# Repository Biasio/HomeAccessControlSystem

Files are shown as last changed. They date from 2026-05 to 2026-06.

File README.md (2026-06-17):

# Home Access Control System 

<!-- TABLE OF CONTENTS -->
<details>
  <summary>Table of Contents</summary>
  <ol>
    <li><a href="#about-the-project">About The Project</a></li>
    <li><a href="#repository-structure">Repository Structure</a></li>
    <li><a href="#hardware-setup">Hardware Setup</a></li>
      <ul>
            <li><a href="#1-rfid-reader">1. RFID Reader</a></li>
            <li><a href="#2-stepper-motor">2. Stepper Motor</a></li>
            <li><a href="#3-display---crystalfontz-128x128-tft-lcd-boostxl-edumkii-onboard">3. Display - Crystalfontz 128x128 TFT LCD (BOOSTXL-EDUMKII Onboard)</a></li>
            <li><a href="#4-input-peripherals-buttons--joystick-boostxl-edumkii-onboard">4. Input Peripherals: Buttons & Joystick (BOOSTXL-EDUMKII Onboard)</a></li>
            <li><a href="#5-piezo-buzzer-boostxl-edumkii-onboard">5. Piezo Buzzer (BOOSTXL-EDUMKII Onboard)</a></li>
            <li><a href="#6-vl53l0x---distance-sensor">6. VL53L0X - Distance Sensor</a></li>
            <li><a href="#7-esp32-s3-uart-communication">7. ESP32-S3 UART Communication</a></li>
            <li><a href="#project-wiring">Project wiring</a></li>
        </ul>
        <li><a href="#software-setup">Software Setup</a>
          <ul>
            <li><a href="#ccstudio-and-simplelink">CCStudio and Simplelink</a></li>
            <li><a href="#telegram-bot">Telegram Bot</a></li>
            <li><a href="#visual-studio-code--platformio">Visual Studio Code + PlatformIO</a></li>
          </ul>
        </li>
      </ul>
    <li><a href="#user-guide">User Guide</a></li>
    <li><a href="#authors">Authors</a></li>
  </ol>
</details>

## About The Project
Welcome to the Home Access Control System!

This project implements a smart door access control system that combines local hardware interaction with IoT remote management.
Users can authenticate using unlock codes, while the administrator can access a dedicated secure menu using an RFID tag.
Beyond the physical interface, an integrated Telegram bot handles remote interactions, enabling the administrator to oversee access permissions and allowing users to request or manage their own codes.
The system also features a database that logs all access events for monitoring purposes.

## Repository Structure

```text
.
├── 3D-Model/                                 # Hardware 3D printable components
│   ├── All components.3mf                    # All components in 1 file
│   ├── door.stl                              # Door model
│   ├── doorframe.3mf                         # Door frame model
│   ├── gear.stl                              # Gear mechanism model
│   ├── sensors_and_peripherals_supports.scad   # OpenSCAD parametric supports
│   └── sensors_and_peripherals_supports.stl    # Exported supports model
├── RepoImages/                               # Documentation media and images
│   ├── HardwareSetup/                        # Schematic diagram
│   ├── SoftwareSetup/                        # Software Setup screenshots
│   │   ├── CCStudio/                         # CCStudio IDE
│   │   ├── FSM/                              # FSM diagram
│   │   └── VSCode+PlatformIO/                # VSCode and PlatformIO IDE
│   └── TelegramBot/                          # Bot usage demonstrations (GIFs & Images)
├── ShortStaysAccessControlSystem/            # Firmware project (MSP432 Microcontroller)
│   ├── msp432p401r.cmd                       # Memory linker script
│   ├── src/                                  # Source code directory
│   │   ├── external_src/                     # External hardware libraries
│   │   │   ├── LCD/                          # Display graphics library
│   │   │   │   ├── Crystalfontz128x128_ST7735.c / .h                     # ST7735 controller primitives
│   │   │   │   └── HAL_MSP_EXP432P401R_Crystalfontz128x128_ST7735.c / .h # Display pin mapping
│   │   │   └── vl53l0x_msp432/               # Distance sensor submodule (Git)
│   │   │       ├── drivers/                  # Sensor native API registers
│   │   │       │   ├── config.h              # Timing configuration
│   │   │       │   ├── i2c.c / .h            # I2C driver
│   │   │       │   ├── macro.h               # Internal macros
│   │   │       │   └── vl53l0x.c / .h        # Main ranging core
│   │   │       ├── main.c                    # Sensor standalone test
│   │   │       └── README.md                 # Submodule info
│   │   ├── buzzer.c / .h                     # Buzzer acoustic alerts
│   │   ├── comm_esp.c / .h                   # Serial communication with ESP32
│   │   ├── database.c / .h                   # Local access credentials memory
│   │   ├── display.c / .h                    # LCD high-level UI menus
│   │   ├── flash.c / .h                      # Flash memory storage driver
│   │   ├── fsm_helpers.c / .h                # State machine utilities
│   │   ├── fsm.c / .h                        # Main application logic (FSM)
│   │   ├── irqHandlers.c / .h                # Hardware interrupt routines
│   │   ├── joystick.c / .h                   # Analog joystick driver
│   │   ├── main.c                            # System entry point & loop
│   │   ├── motor.c / .h                      # Motor control driver
│   │   ├── push_button.c / .h                # Buttons and debouncing
│   │   ├── sensors.c / .h                    # RFID and Distance sensor drivers
│   │   └── timers.c / .h                     # Periodic timer configurations
│   ├── startup_msp432p401r_ccs.c             # Microcontroller vector table
│   ├── system_msp432p401r.c                  # System clock configuration
│   └── targetConfigs/                        # IDE target configurations
│       ├── MSP432P401R.ccxml                 # Target configuration file
│       └── readme.txt                        # Target config info
├── TelegramBot/                              # PlatformIO project (ESP32 Microcontroller)
│   ├── include/                              # Global header files
│   │   ├── credential-template.h             # Wi-Fi and Token template
│   │   └── README.md                         # Folder info
│   ├── lib/                                  # Custom local libraries
│   │   ├── DoorBotManager/                   # Telegram connection & events logic
│   │   │   ├── DoorBotManager.cpp            # Bot API implementation
│   │   │   └── DoorBotManager.h              # Bot class definition
│   │   └── README.md                         # Lib folder info
│   ├── platformio.ini                        # Build and dependency settings
│   ├── src/                                  # Application source code
│   │   ├── idf_component.yml                 # ESP-IDF component packages
│   │   └── main.cpp                          # Main bot loop & Wi-Fi init
│   └── test/                                 # Unit testing folder
│       └── README.md                         # Test folder info
├── HomeAccessControlSystem-Presentation.pdf  # Project presentation
└── README.md                                 # Project documentation
```

## Hardware Setup 

To securely isolate local hardware operations from network tasks, the system architecture is divided between two interconnected microcontrollers:

- **Texas Instruments MSP432P401R**: The core of the system, interfaced with the **Educational BoosterPack MKII (BOOSTXL-EDUMKII)**. It handles several external and onboard sensors and actuators to manage physical access control and user interaction.

- **Espressif ESP32-S3**: Operating as a dedicated network coprocessor, it connects to the MSP to handle all Wi-Fi connectivity, system time synchronization, and the Telegram Bot logic.

Below is the technical breakdown of each hardware module integrated into the system, including their designated communication protocols, pin mapping, and core logic.

### 1. RFID Reader
Handles secure tag scanning and authentication, granting administrator-level access to the local configuration menu.

* **Communication Protocol:** `SPI`
* **Hardware Connections:**
  * `SDA / CS`: Pin `[5.2]`
  * `SCK`: Pin `[3.5]`
  * `MOSI`: Pin `[3.6]`
  * `MISO`: Pin `[3.7]`
  * `RST`: Pin `[3.0]`

#### Core Implementation

##### Initialisation (`RFID_Init`)
```c
Configure SPI pins (SCK, MOSI, MISO, CS, RST) as peripherals
Set CS high (idle)
Pull RST low for 1 ms, then high (hard reset)
Set SPI master: 4 MHz, mode 0, MSB first
Keep SPI module disabled (RFID_ready = false)
```

##### Enable (`RFID_Enable`)
```c
if not RFID_ready:
    RFID_Init()
Enable SPI module
Set RST high, delay 50 ms for boot up

Soft reset MFRC522

Verify version (0x37) == 0x91 or 0x92, if invalid: return false

Configure the onboard timer
Set RxGain
Enable the antenna: set bit0 and bit1 of TxControlReg (0x14)

RFID_ready = true 
return true
```

##### Disable (`RFID_Disable`)
```c
Set CS high
Disable SPI module
Set RST high (inactive)
Restore pins as inputs with pull‑ups (shared with the A_button)
Re‑initialise display and buttons
RFID_ready = false
```

##### Read Tag (`RFID_ReadTag`)
```c
REQA request, if response length < 2 bytes: return false

Anticollision command - multiple cards could be present at the same time. If response length < 5 bytes: return false

Checksum check, if it fails return false

return the UID
```

##### Tag Validation & Error Handling

**Used for standard admin access (in `wait_RFID` or `block_RFID`)**
```c
if not RFID_Enable() show "ERROR" and return false

while true:
    if buttonA_pressed: 
        RFID_Disable(); return false   // cancel (for wait_RFID only)

    if RFID_ReadTag(uid, &len) succeeded:
            if the tag is valid and correct:
	    	show "VALID RFID" and play the correct sound
            	return true
	    else:
		RFID_Disable()
	        show "WRONG RFID", play wrong sound
	        return false
    else:
        delay_ms(50)    // no tag, keep polling after a short delay
```

**Error checks and resilience**:
The RFID driver includes exhaustive checks for every SPI transaction (timeouts, protocol errors, collisions, CRC mismatches, and FIFO emptiness) and validates the UID checksum before accepting a read.
If a critical error occurs (e.g., version mismatch after soft reset), it automatically re‑initialises the module; otherwise, it safely disables the SPI interface and restores pin functions, preventing hangs or bus conflicts.

### 3. Stepper Motor
Actuates the physical locking and unlocking mechanism of the door via precise rotational control.

* **Communication Protocol:** `ULN2003 driver`
* **Hardware Connections:**
  * `IN1`: Pin `[2.5]`
  * `IN2`: Pin `[6.6]`
  * `IN3`: Pin `[6.7]`
  * `IN4`: Pin `[2.3]`

#### Core Features
* **Angle-based Control:** Converts a given angle into the number of steps required by the 28BYJ-48 Stepper Motor. 
* **Safe locking/unlocking Mechanism:** Saving in Flash memory a dedicated flag, ensures protection against two straight opening (or closing) cycles which can damage door mechanism. Pretty useful in case of power failure. 
* **Full-Step Drive:** Supplying power to two coils simultaneously, the Motor gives the maximum available torque and holding force. This ensures reliability when opening/closing the door. 
* **External Power Supply:** To avoid over-heating and self-reset procedure on the MSP-board due to over-current demanding, the Motor Driver is feed with an external 5V Power Source.

#### Core Implementation
```c
moveMotor(int angle):      //This function converts the given angle into the number of steps required and manages motor movement
    calculate number of steps required to turn motor on the given angle    
    
    if the number of steps is negative:
        Motor needs to run counterClockwise
    else:
        Motor runs clockwise

    calculate index for the For-cycle, depending in which direction Motor should run

    for each step Motor will make:

        for each pin:
          
          if the associated coil should go high:
            Set pin high
          else:
            Set pin low

        wait before the next step

   before returning from the function, set all pins low  
```

### 3. Display - Crystalfontz 128x128 TFT LCD (BOOSTXL-EDUMKII Onboard)

The **Crystalfontz CFAF128128B-0145T color 128x128-pixel TFT LCD** renders the local Graphical User Interface (GUI), to display the keypad interface and the admin menu.

* **Communication Protocol:** `SPI`
* **Hardware Connections:**
  * `LCD_SCLK`: Pin `P1.5`
  * `LCD_MOSI`: Pin `P1.6`
  * `LCD_CS`: Pin `P5.0`
  * `LCD_RST`: Pin `P5.7` 
  * `LCD_BACKLIGHT`: Pin `P3.7` 

#### Core UI Features
* **Numeric PIN Grid:** Renders a 3x4 interactive keypad interface for standard user authentication.
* **Administrator Menu:** A scrollable, paginated menu allowing authorized admins to view the last access log and manually lock and unlock the door and clear the database.
* **Dynamic Joystick Navigation:** Translates raw X/Y analog inputs from the joystick to move a red selection rectangle (`Rectangle` struct) across the screen, supporting both grid-based navigation and vertical menu scrolling.
* **Interactive Selection & Feedback:** Evaluates the position of the selection rectangle against a predefined array of coordinates (e.g., `GRID_POINTS`). When a user confirms a selection, the system executes a temporary visual flash (red-to-white fill) over the selected item to provide immediate confirmation feedback.
* **System Status Prompts:** Delivers instant, color-coded visual alerts for real-time events (e.g., `display_door_open()`, `display_wrong_pin()`, `display_block_access()`).

#### Core Implementation

```c
// Initialize the graphics context, display orientation, and default fonts
graphicsInit():
    initialize LCD hardware
    set colors, font and orientation UP

// Routes joystick input to update the UI based on the active screen state
move_rectangle_on_display(x, y, grid_on):
    if grid_on:
        calculate bounds and shift selection box across numeric keypad
    else:
        handle vertical scrolling, pagination, and highlighting in Admin Menu

// Detects selected grid point and triggers visual feedback
number_selected():
    for each point in GRID_POINTS:
        if the point is inside the selection rectangle:
            trigger visual flash feedback
            return point_index        
    return -1    // no number selected

```

### 4. Input Peripherals: Buttons & Joystick (BOOSTXL-EDUMKII Onboard)
Captures analog and digital user inputs for menu navigation, selection, and system interaction. 

* **Communication Protocol:** `GPIO` (Digital Input with Interrupts) & `ADC` (Analog-to-Digital Converter)
* **Hardware Connections:**
  * `Button 1`: Pin `P5.1`
  * `Button 2`: Pin `P3.5`
  * `Joystick X-Axis`: Pin `P6.0`
  * `Joystick Y-Axis`: Pin `P4.4`

#### Core Features
* **Interrupt-Driven Architecture:** Utilizes hardware interrupts for both the ADC (joystick) and GPIO (buttons) to capture inputs asynchronously. This prevents the system from blocking the main execution loop while waiting for user interaction.
* **Pull-Up Configuration:** Pushbuttons are configured with internal pull-up resistors, meaning they trigger on a high-to-low voltage transition (active-low) when pressed.
* **Timer-Based Software Debouncing:** To prevent mechanical switch bounce from registering as multiple rapid presses, the system temporarily disables the button interrupt and triggers a hardware timer. The input state is only validated after the timer expires.

#### Core Implementation
```c
ADC_interrupt():
    if conversion_finished:
        joystick_X = read_ADC(X_channel)
        joystick_Y = read_ADC(Y_channel)
        set move_rectangle_flag       // trigger UI update
        restart joystick_timer

GPIO_button_interrupt():
    if button1_triggered:
        initiate_debounce_sequence()
        return

initiate_debounce_sequence():
    disable button interrupts         // ignore mechanical switch bounce
    start debounce_timer              // wait for signal to stabilize

debounce_timer_interrupt():
    stop debounce_timer

    if button1 is still pressed:
        set button1_pressed_flag
        reset UI_timeout_timer

    if button2 is still pressed:
        set button2_pressed_flag
        reset UI_timeout_timer

    re-enable button interrupts       // ready for next press
```

### 5. Piezo Buzzer

Generates acoustic feedback for successful actions (correct PIN, valid RFID), wrong attempts, and system lockout.
Comes with a configurable VOLUME 
* **Communication Protocol:** `PWM` (Pulse Width Modulation)
* **Hardware Connections:**
  * `Signal`: Pin `P2.7` (Timer_A0 capture/compare output 4)

#### Core Implementation

##### Initialisation (`_buzzerInit`)
```c
Stop Timer_A0
Disable the timer interrupts and clear any pending interrupt flag
Configure P2.7 as peripheral output (primary module function)
```

##### PWM Configuration Structure
```c
Timer_A_PWMConfig {
    clockSource: SMCLK
    clockDivider: 16
    timerPeriod: calculated as a function of the notes
    compareRegister: 4
    outputMode: RESET_SET
    dutyCycle: calculated as a function of the notes
}
```

##### Play a Song (`buzzerPWMgen`)
```c
For each note in the song:
    if volume != 0 and freq != 0:
        timerPeriod = ((SMCLK frequency) / (freq × 16)) & (0xFFFF) // clamped to 16‑bit]
        dutyCycle = (timerPeriod × volume) >> 10
        Configure and start PWM with this period/duty
        delay for the note.duration
        dutyCycle = 0 → stop PWM
        delay_ms(1)   // short silence between notes
    else:
        Stop timer (no sound)
```
All sequences are blocking (delay-based) and play to completion before returning control to the caller.

##### Pre‑defined Sounds

| Sound         |
|---------------|
| `CorrectPin`  |
| `WrongPin`    |
| `LockOut`     |
| `CorrectRFID` |

### 6. VL53L0X - Distance Sensor
Detects user proximity to wake the system from low‑power mode, configured to trigger an interrupt when a target is closer than 300 mm (src/external_src/vl53l0x_msp432/drivers/config.h).

* **Communication Protocol:** `I²C`
* **Hardware Connections:**
  * `SCL`: Pin `P6.5`
  * `SDA`: Pin `P6.4`
  * `XSHUT`: Pin `P4.1` (hardware reset / power enable)
  * `INTERRUPT`: Pin `P4.6` (active‑low)

#### Core Implementation

##### Initialisation (`ToF_Init`)
```c
Configure XSHUT as output, pull low (sensor in reset)
Initialise I²C master (EUSCI_B1, speed: 400 kHz, clk source: SMCLK)
Configure interrupt pin as input with pull‑up, edge‑triggered (falling edge)
```

##### Enable (`ToF_enable`)
```c
Release XSHUT (high) and wait for sensor boot
vl53l0x_init():
    - I²C slave address set to default address (0x29)
    - load SPAD configuration from NVM
    - Load default tuning settings
    - Set signal rate limit (0.25 MCPS) and timing budget (33 ms) for average light conditions
    - Run VHV and phase calibrations

Call vl53l0x_start_continuous(): arms continuous back‑to‑back ranging

Clear any pending interrupt on sensor

Enable GPIO interrupt on P4.6

ToF_ready = true
```

##### Disable (`ToF_disable`)
```c
Disable GPIO interrupt on P4.6

Call vl53l0x_stop_continuous() halts the ranging engine and clears interrupt register

Pull XSHUT low (sensor in hardware standby)

ToF_ready = false
ToF_flag = 0
```

##### Interrupt Handling (`ToF_IRQHandler`)
```c
Disable further interrupts on P4.6
Clear interrupt flag on GPIO

If ToF_ready: set ToF_flag = 1
```

##### Proximity Detection Flow
```c
System in `STATE_AOD` with sensor enabled

User approaches, sensor crosses 300 mm threshold and INT pin asserts

`ToF_flag` set so `check_for_inputs()` evaluates the ToF reading via `vl53l0x_read_range_interrupt()`

If range ≤ low_threshold && the error code is valid:
	 disable the sensor and wake system to `STATE_INSERT_PIN`
   else:
	reactivate the interrupt for ToF and go to sleep
```
#### Error checks and resilience
The VL53L0X driver implements automatic init retries (up to 2 attempts) if initialisation or continuous ranging start fails. 
Every I2C transaction includes NACK detection and timeout checks to prevent hanging or corrupted configuration in registers I/O operations.

### 7. ESP32-S3 UART Communication

An `UART` serial communication interface was configured to enable data exchange and command execution between the two microcontrollers.

* **Communication Protocol:** `UART`

* **Hardware Connections:**
  * Texas Instruments MSP432P401R:
    * TX: Pin `P3.3`
    * RX: Pin `P3.2`
  * Espressif ESP32-S3:
    * TX: Pin `P17`
    * RX: Pin `P16`

#### Core Features

* **Message Handling & Dispatching:** Uses hardware interrupts (`EUSCIA2_IRQHandler`) to asynchronously buffer incoming messages and routes them to specific handlers based on predefined prefixes (`processUartMessage`).

* **PIN Management:** Manages access by generating unique 4-digit PINs (`handleGenTempPin`), verifying user inputs against stored credentials (`handleVerifyPin`), and processing early revocation requests (`handleRevokePin`).

* **Time Synchronization:** Requests network time (`requestRealTime`) and parses the ESP32 payload to accurately configure the hardware Real-Time Clock (`handleTimeSync`).

### Project wiring
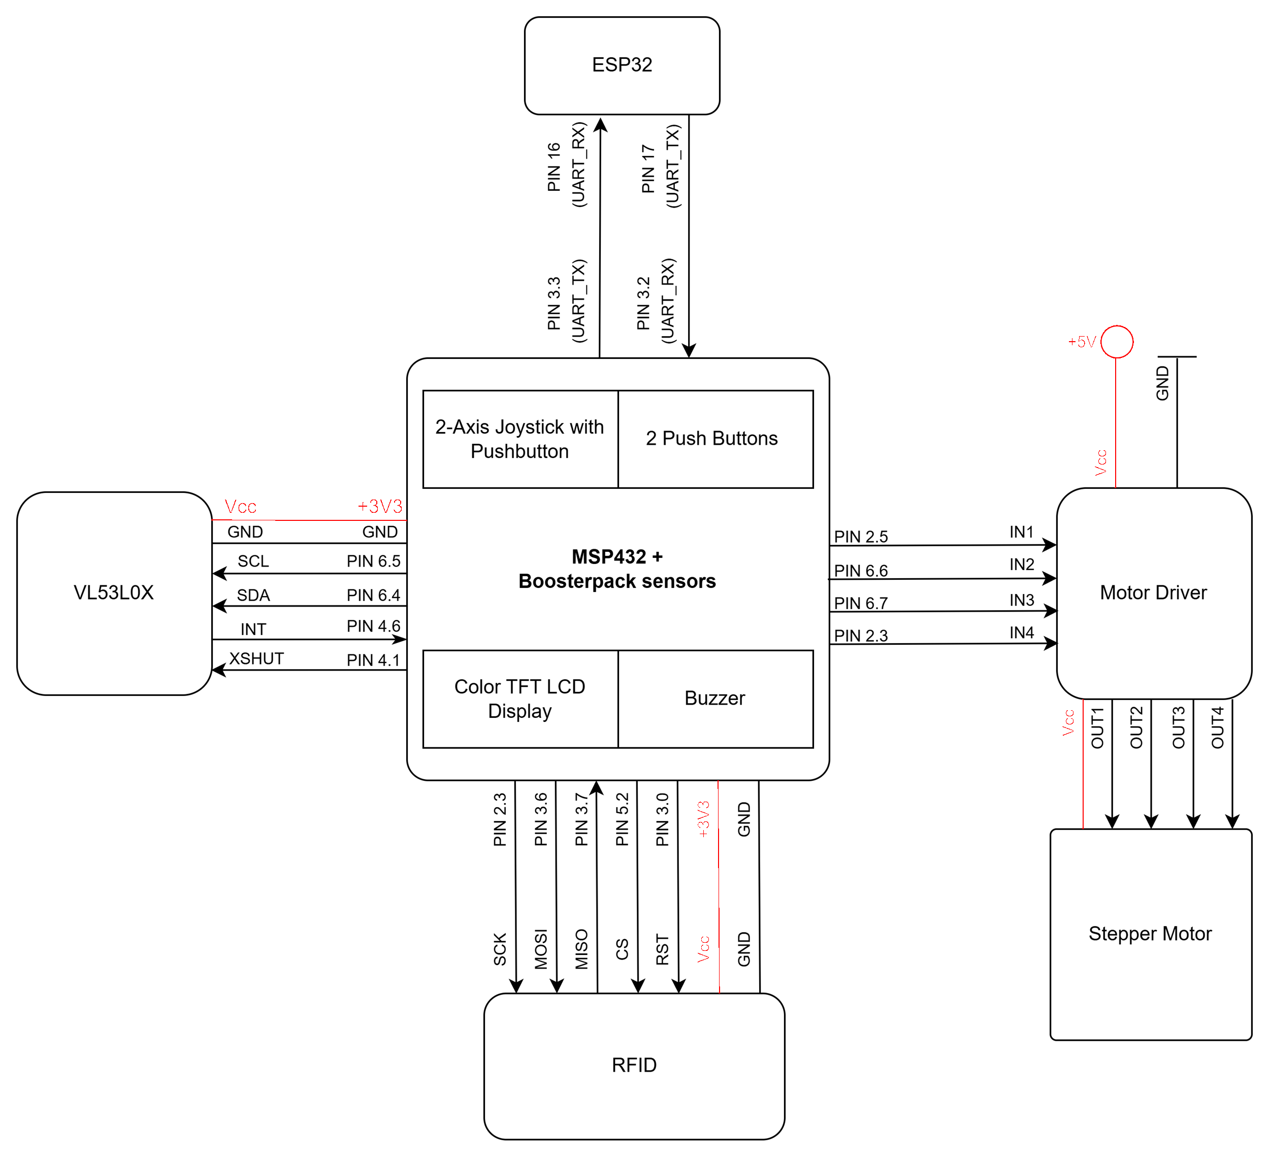
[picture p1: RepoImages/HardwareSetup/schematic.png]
Schematic of the project


## Software Setup

### CCStudio and Simplelink

1. First, clone the repository with git

```bash
git clone <repository-url>
cd <repository-folder>
git submodule init && git submodule update --remote
```

2. Then download [**CCStudio v12.8**](https://www.ti.com/tool/download/CCSTUDIO/12.8.1) and [**SimpleLink MSP432 SDK v3.40.01.02**](https://www.ti.com/tool/download/SIMPLELINK-MSP432-SDK/3.40.01.02)

> ⚠️ **Important:** The SimpleLink SDK must be placed in the **parent directory** of the repository (i.e., the folder that will contain the cloned repo). For example, if you pln
 to clone into `~/my_project`, the SDK should be extracted to `~/` (so the SDK folder sits alongside `my_project`, not inside it).

3. Now you can import the project in CCStudio:
    - Launch **CCStudio v12.8**
    - When prompted for a workspace, select the **repository folder** (the one you just cloned)
    - Go to **Project → Import Project** (or **File → Import** → **CCS Projects**)
    - Click **Browse…** and select the repository folder
    - Under **Discovered Projects**, check the project you want to import
    - Click **Finish**

4. The MSP432 program can be now uploaded to the board.

### Telegram Bot

1. Download and install Telegram on your device. We recommend using the [Telegram Desktop application](https://desktop.telegram.org/) on your PC for a more comfortable setup experience.
Open this link [**@BotFather**](https://t.me/BotFather) to launch the official bot creation tool in Telegram, then start the conversation by sending the command `/start`.
3. Send the command `/newbot` to create a new bot.
4. Follow **@BotFather**'s instructions to configure your bot:
   * First, choose a **name** for your bot (this is the display name users will see).
   * Then, choose a unique **username** (it must end with `bot`, e.g., `HomeAccess_bot`).
5. Once the bot is created, BotFather will send you a confirmation message containing your **HTTP API Token**. Copy and save this token securely, as you will need to insert it into the project file for the ESP firmware, as explained in the following section.
6. To configure the bot's menu, send the command `/setcommands` to **@BotFather**.
7. Select your newly created bot from the provided list, then copy and paste the following text into the chat to set up your commands:

```
start - Initialize the bot and authenticate yourself
menu - Display the main control panel and available features
cancel - Abort the current operation or transaction
```

### Visual Studio Code + PlatformIO

1. Download and install [Visual Studio Code](https://code.visualstudio.com/download).
2. Install the [PlatformIO IDE Extension](https://docs.platformio.org/en/latest/what-is-platformio.html) from the VSCode extensions marketplace.

<p align="center">
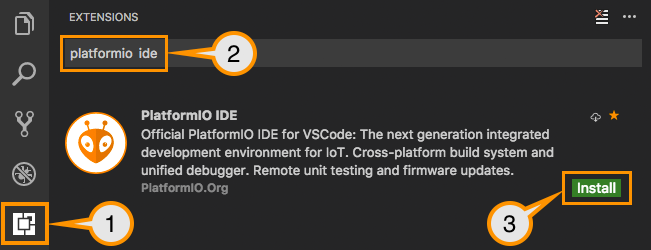
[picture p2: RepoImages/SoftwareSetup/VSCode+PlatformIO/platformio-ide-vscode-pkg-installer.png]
  
</p> 

3. Click the PlatformIO icon on the left sidebar. You will see the screen shown in the image below. Click the **Pick a folder** button. Navigate to the location where you cloned the `HomeAccessControlSystem` repository and select the `TelegramBot` folder inside it to open the project.

<p align="center">
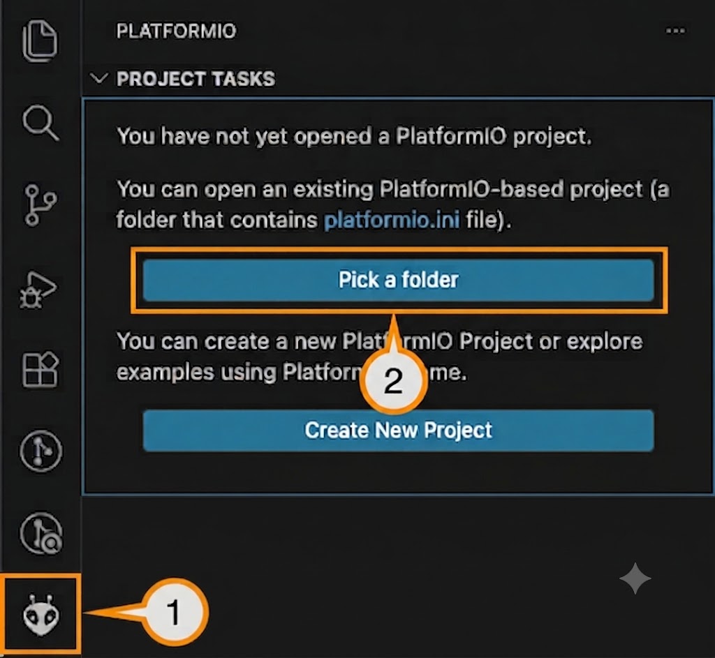
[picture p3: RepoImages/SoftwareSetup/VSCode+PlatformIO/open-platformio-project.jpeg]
  
</p> 

4. Open the configuration file located at `TelegramBot/include/credential-template.h` starting from the root of the repository.

5. Insert your Wi-Fi credentials and the Telegram Bot token you saved earlier by replacing the placeholder text inside the quotes "":

<p align="center">
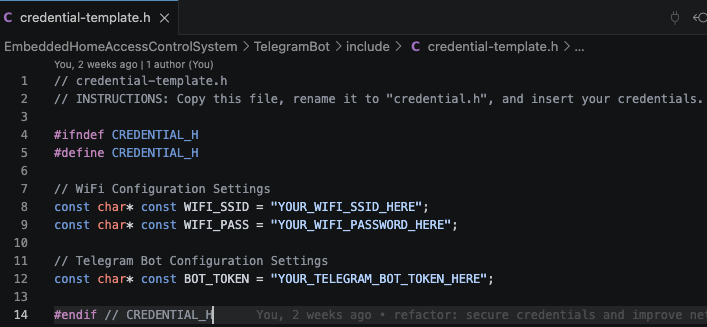
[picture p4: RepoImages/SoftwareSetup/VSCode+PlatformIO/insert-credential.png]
  
</p> 

6. Copy and rename the file from `credential-template.h` to `credential.h`. This ensures your sensitive credentials are not accidentally uploaded to GitHub if you push your changes, as `credential.h` is already included in the `TelegramBot` project's `.gitignore` file.

7. Connect a microUSB cable to the **UART** port on your **ESP32-S3 board**. Go to the top right corner where the **Build** icon (the checkmark) is located, click the down arrow symbol next to it, and select **Upload** to compile the code and upload the firmware.

> **Note:** The first time you perform this action, it will take some time. PlatformIO works in the background to automatically download all the necessary libraries and the updated Arduino core directly from the official Espressif repository.

## User Guide

This section explains how to interact with the system through its physical display and the Telegram bot.

Click here to watch:
- [Link to the presentation](HomeAccessControlSystem-Presentation.pdf)
- [Link to the video](https://youtu.be/aaDjH45Er1A)

### System Interface

#### 1. MSP User interface

<div align="center">
  <table border="0" style="border: none; background: none;">
    <tr style="border: none; background: none;">
      <td align="center" width="50%" style="border: none; padding: 10px;">
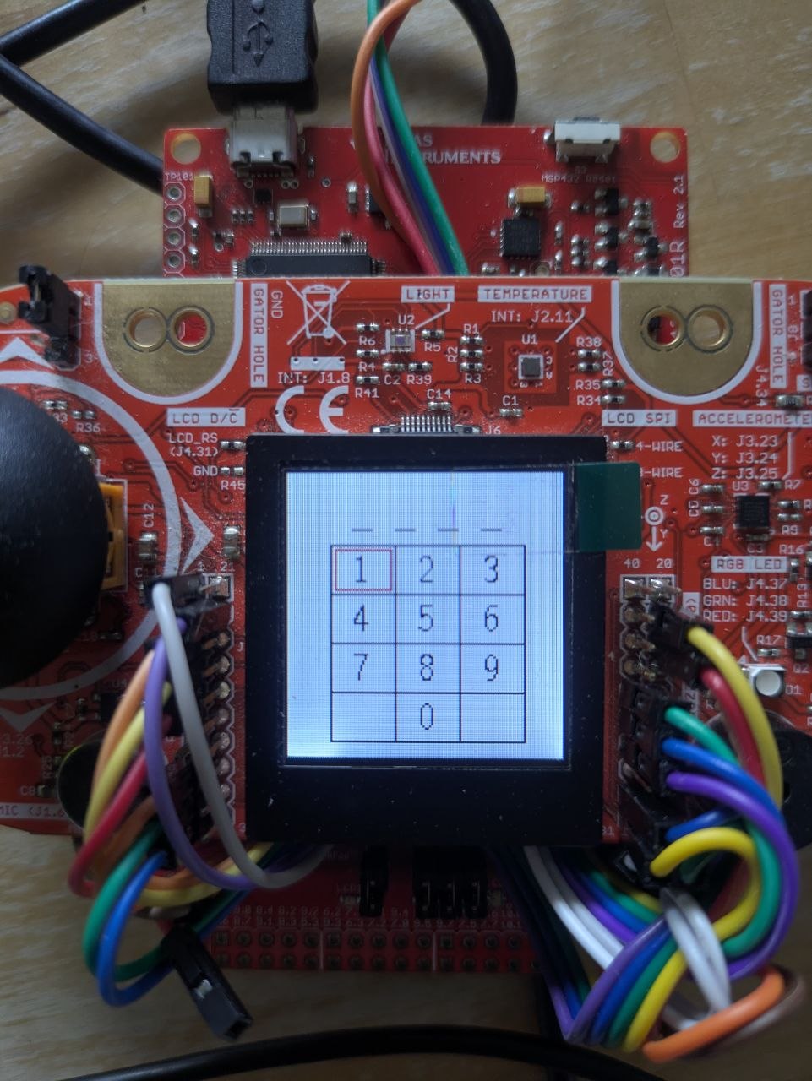
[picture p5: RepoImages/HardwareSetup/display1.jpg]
User display
        
      </td>
      <td align="center" width="50%" style="border: none; padding: 10px;">
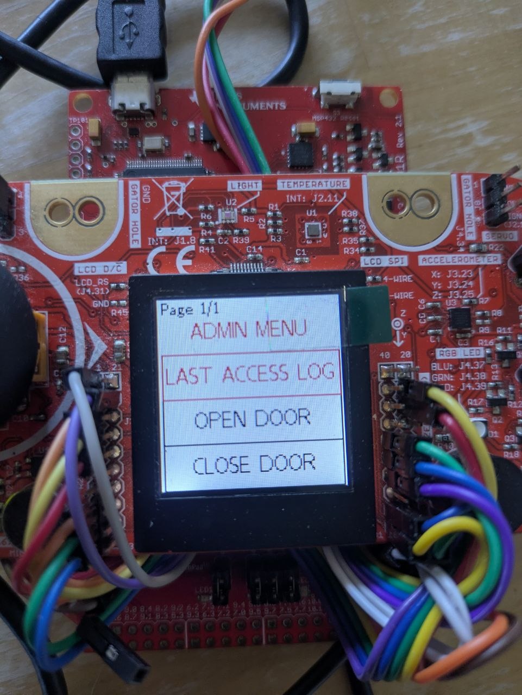
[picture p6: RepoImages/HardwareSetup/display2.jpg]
User display
        
      </td>
    </tr>
  </table>
</div>

The physical interface features an TFT LCD screen controlled by the onboard joystick and push buttons. The first image shows the numeric keypad, where users navigate to enter their 4-digit access PIN. The second image displays the Admin Menu, accessible exclusively with his PIN and RFID tag.

#### 2. Database

When logged as Admin, the system allows you to see and to navigate through an interactive “Log Database”, which stores in permanent memory (Flash) the last 10 autentication data remembering the moment of the access, the used PIN and if it has been recognised as the Admin one, as one of the Users or none.  

<p align="center">
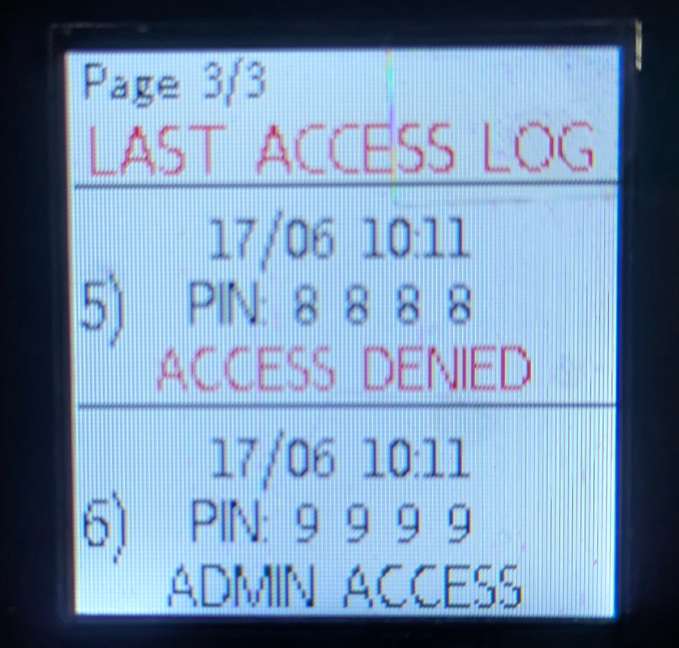
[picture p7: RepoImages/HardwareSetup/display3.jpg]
Access log page
  
</p> 

##### Core features

* **Interactive Navigation:** Using the on-board joystick, the Admin can browse the different Database pages containing all log data.

* **Quick Save:** During initialization instructions, info stored in Flash memory are copied in a RAM instance to be modified and to be shown. When a new log event is added, the systems quickly upload these modifications in the permanent memory ensuring any data lost due to power faults.

* **Blocked User Access:** The Home Access Control System checks when User access is denied multiple times, blocking it when a maximum number of tries is exceeded, until the Admin uses his RFID tag. To prevent an intruder from bypassing this check, a Boolean flag is stored in Flash memory with Database data so the system can remember, in case it’s turned off, that the Admin action is required to proceed with normal activities.

### Telegram Bot Interface

- First of all, search for your bot in Telegram using the **@username** you assigned to it during the BotFather setup (refer to the previous **Software setup section**).
- Now, you can initiate the conversation by pressing the **Start** button at the bottom of the chat or by typing the `/start` command. You will receive a prompt asking you to authenticate as either an **Admin** or a **User**.
- If you choose to log in as an **Admin**, the bot will ask for an unlock code. Currently, this code is hardcoded as `9999`.

- Once authenticated, the main command dashboard will appear. You can always bring up this dashboard again at any time by sending the `/menu` command (this applies to both Admin and Users).

<p align="center">
  
</p> 

**Admin Features**
When logged in as an Admin, your dashboard will include the following functions:
1. `Pin Duration`: Set the validity time limit for the temporary pins granted to Users.

<p align="center">
  
</p> 

2. `Remove User`: Remove a specific User entirely from the system.

<p align="center">
  
</p>

3. `Revoke all PINS`: Revoke all currently active unlock pins for all users in the system.

Beyond the dashboard, the main Admin's feature is receiving direct notifications to either approve or deny user pin requests.

<p align="center">
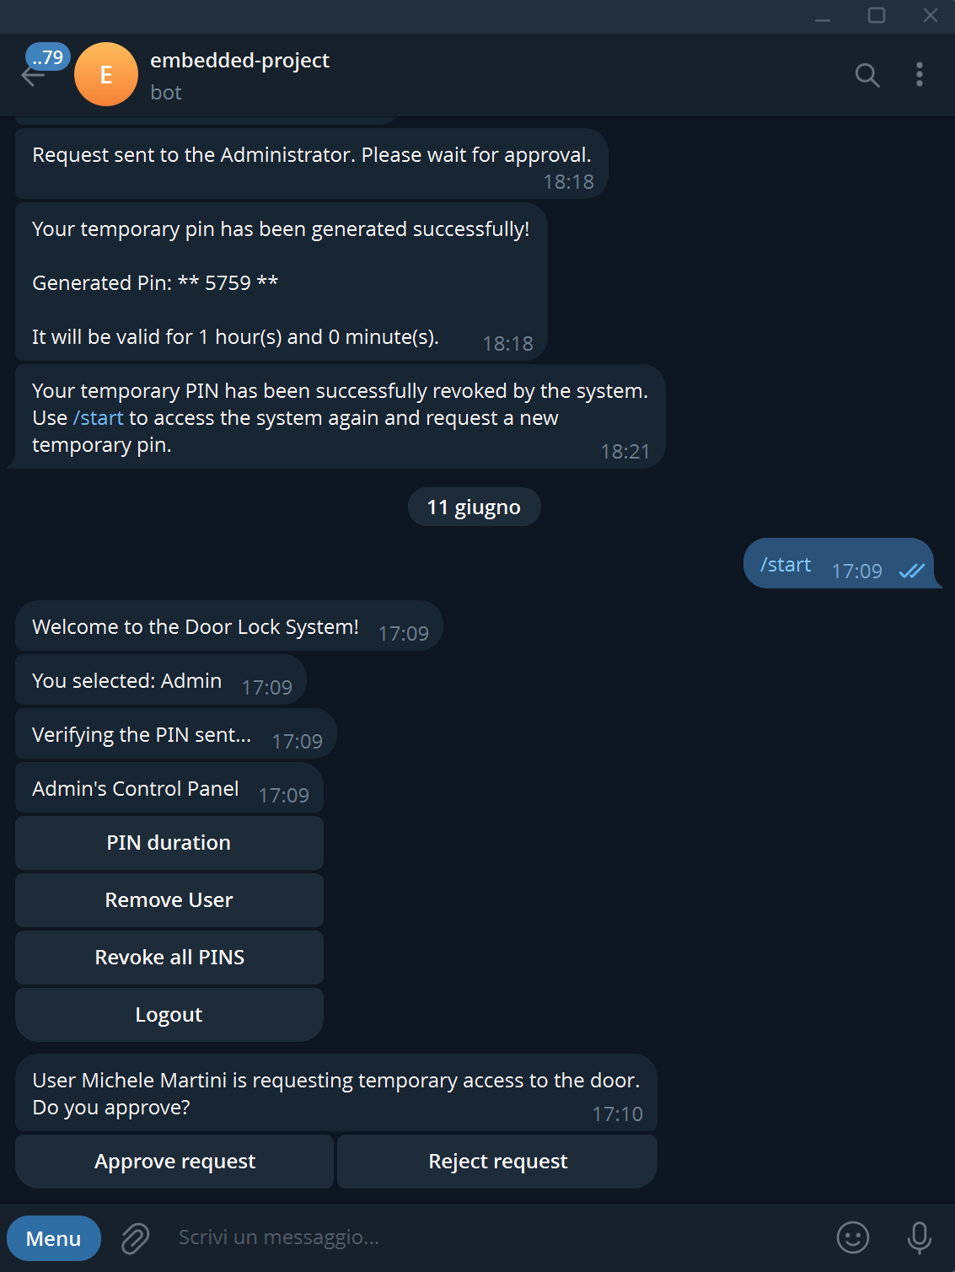
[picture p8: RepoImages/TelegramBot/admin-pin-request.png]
  
</p>

**User Features**
When logged in as a User, your dashboard adapts based on your current access status:
1. `Request Temporary Pin`: After the authentication, this is the only available action. Use it to send an access pin request to the Admin.

<p align="center">
  
</p>

2. `Temporary Pin Duration`: Once the Admin grants you a pin, use this button to check how much validity time is left before it expires.

<p align="center">
  
</p>

3. `Revoke Temporary Pin`: If you no longer need access, use this to manually revoke your own active pin early.

<p align="center">
  
</p>

## Authors

* **Pietro Baroni:**
  * MSP432 FSM structure
  * Display API and menus
  * Joystick ADC
  * Push buttons

* **Michele Martini:**
  * Telegram bot
  * ESP32 FSM
  * UART Communication

* **Michele Casagrande:**
  * Flash I/O operations
  * Database API
  * Stepper motor integration

* **Alessandro Biasioli:**
  * RFID setup, logic and communication
  * ToF Sensor bare-metal driver and logic
  * Buzzer 
  * MCU sleep and AoD logic

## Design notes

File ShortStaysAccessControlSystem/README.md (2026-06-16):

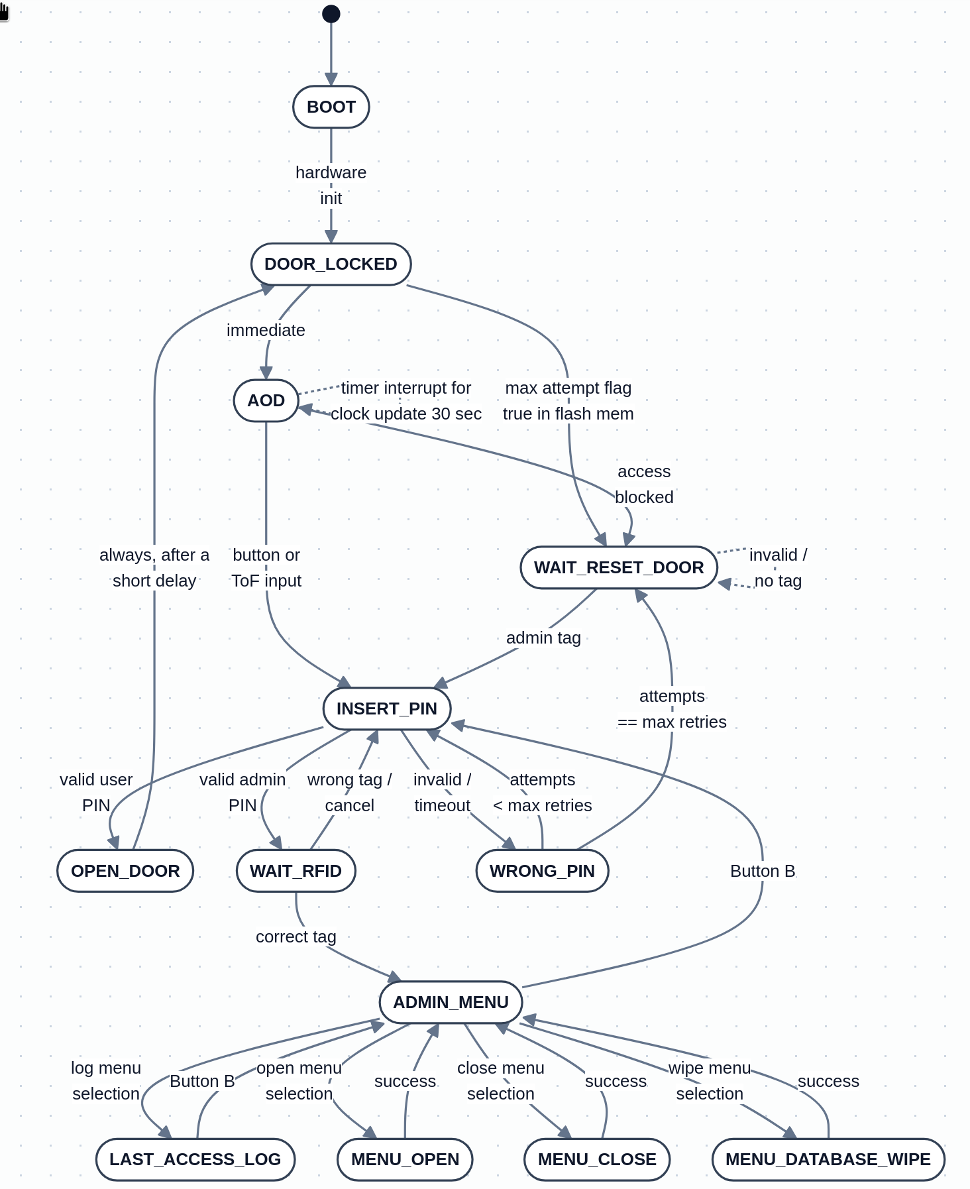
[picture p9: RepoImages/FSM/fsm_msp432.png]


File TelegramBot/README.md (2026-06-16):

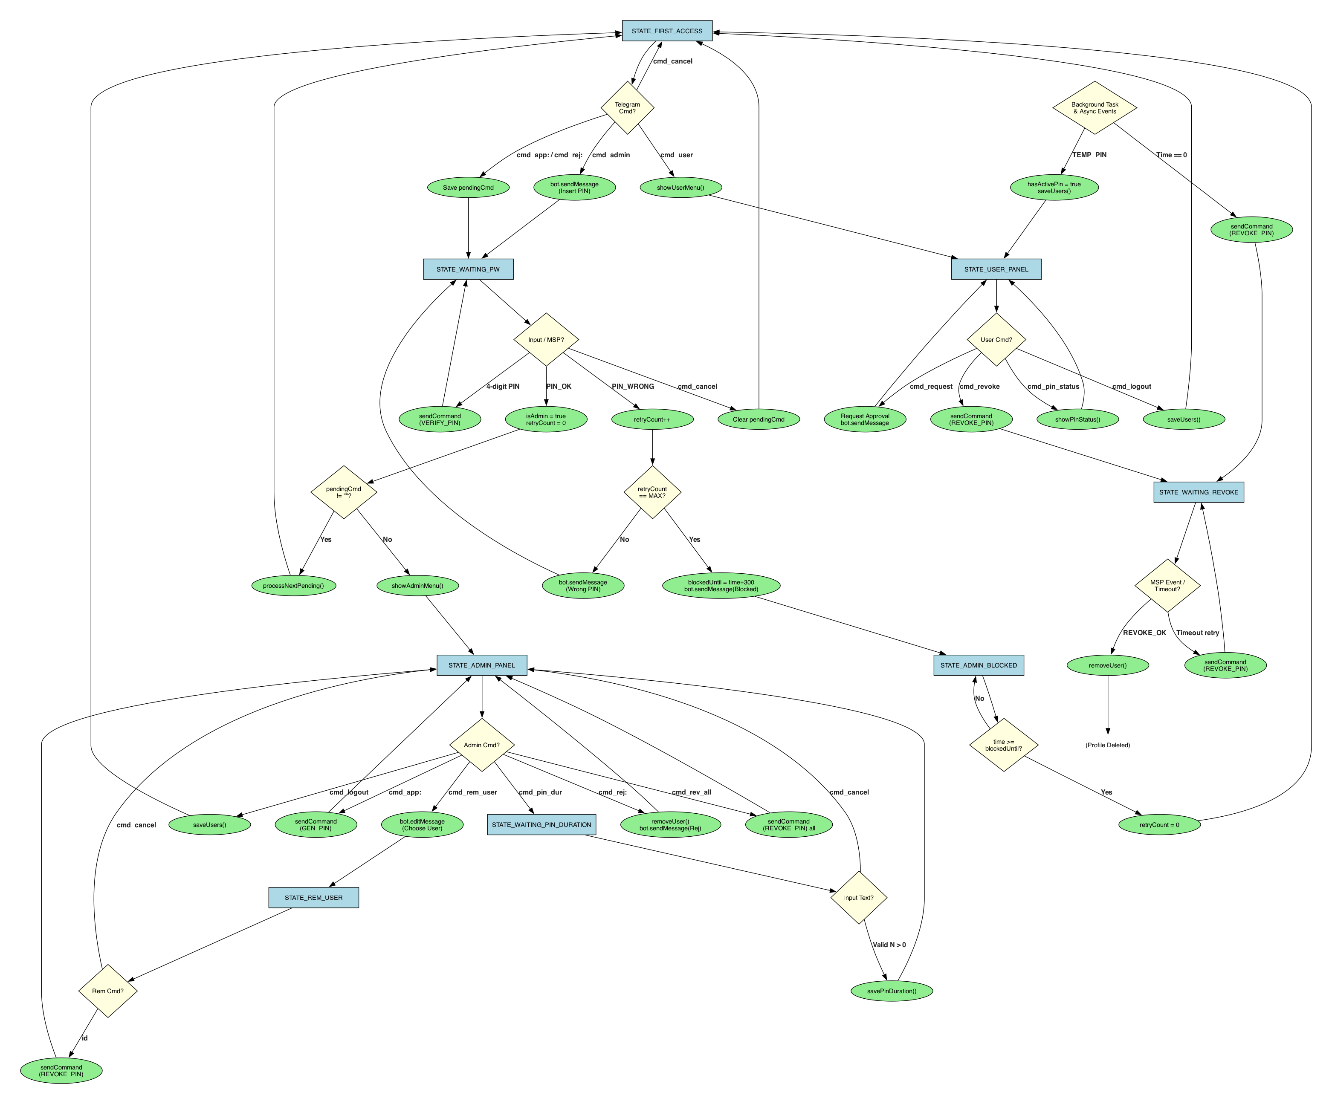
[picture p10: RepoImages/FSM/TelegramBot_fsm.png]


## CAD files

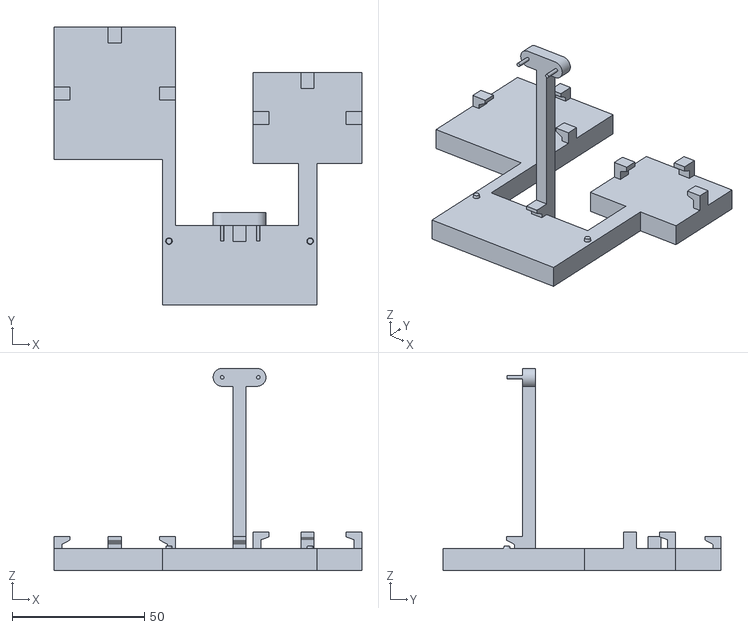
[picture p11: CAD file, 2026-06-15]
3D-Model/sensors_and_peripherals_supports_top.stl
116.6 x 105.2 x 76.6

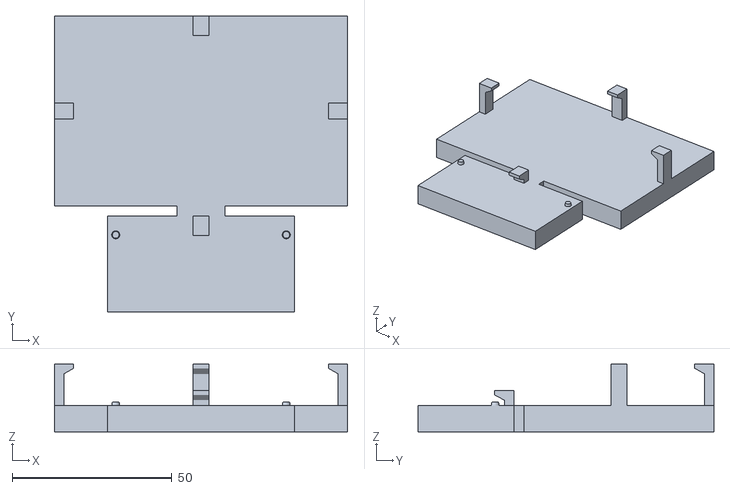
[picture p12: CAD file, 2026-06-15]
3D-Model/sensors_and_peripherals_supports_bottom.stl
91.8 x 92.7 x 21.2

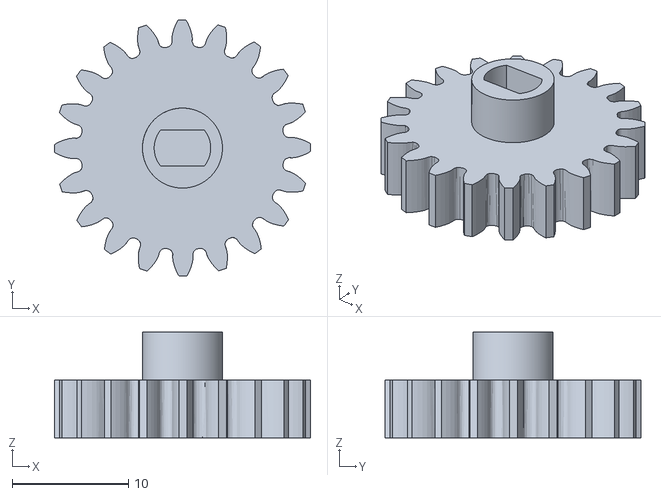
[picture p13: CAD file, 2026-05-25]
3D-Model/gear.stl
22.0 x 22.0 x 9.10

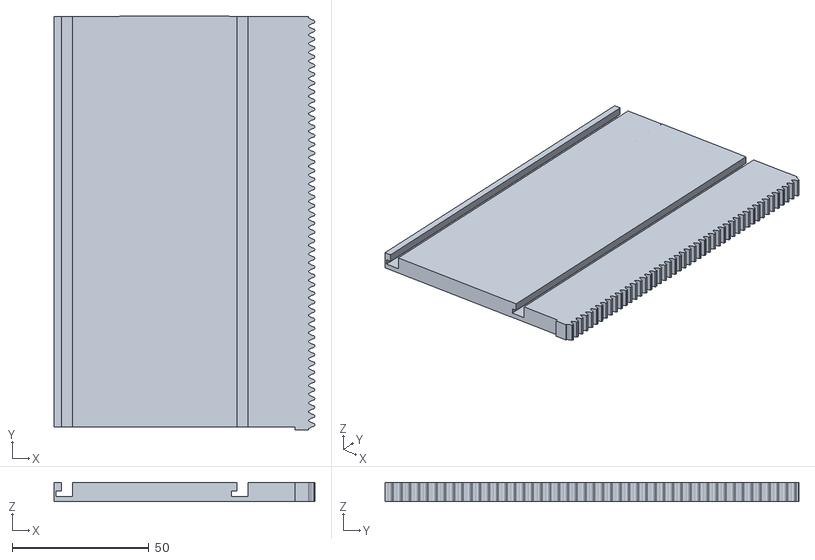
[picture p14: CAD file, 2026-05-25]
3D-Model/door.stl
95.3 x 151.0 x 7.10

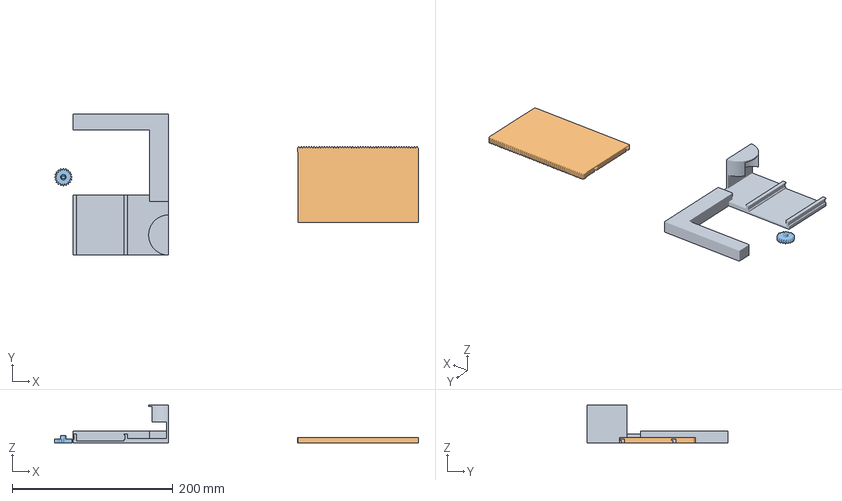
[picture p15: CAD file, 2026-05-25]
3D-Model/All components.3mf
453.6 x 176.0 x 47.3 mm
doorframe
door.stl
gear.stl

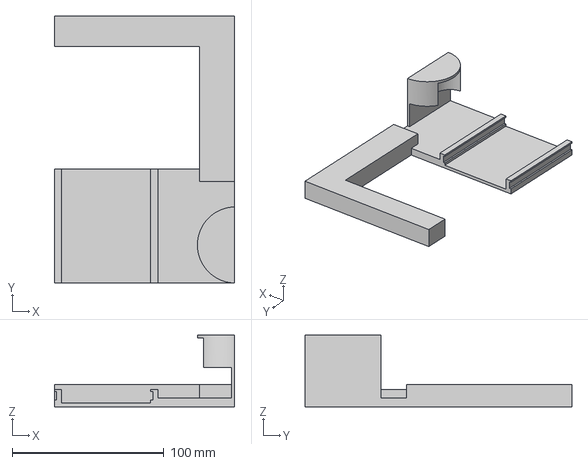
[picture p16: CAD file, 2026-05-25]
3D-Model/doorframe.3mf
118.8 x 176.0 x 47.3 mm

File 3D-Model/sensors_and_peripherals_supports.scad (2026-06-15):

$fn=100;
$fa=0.1;
//comprehensive of the diameters of the holes
board_hole_horiz_dist = 56.45;
board_hole_diameter = 3;
height_to_board = 8.3;
board_width = 58.5;
board_thickness=1.5;
base_length=30;
tolerance=0.01;

base_wall_external=2;

hole_perimeter_to_board_edge=1.2;

notch_width=5;
notch_length=3;
notch_thickness=3;
notch_height=board_thickness*1.1;




RFID_hole_to_board_distance=25;
RFID_width=40;
RFID_length=60-12.8;



vl53l0x_height=60; //from board top




// apply tolerances
fixed_board_hole_r=board_hole_diameter/2-tolerance;
fixed_height_to_board=height_to_board-tolerance;

hole_cone_base_r=fixed_board_hole_r*0.9;
hole_cone_top_r=fixed_board_hole_r*0.7;





//base cube
module base_cube(width=board_width,length=base_length,height=fixed_height_to_board){
        difference(){
            cube([width,
                length,
                height], 
                center=true);
 
            translate([0,0,-base_wall_external])
            cube([width - 2*base_wall_external,
                length - 2*base_wall_external,
                height], 
                center=true);
        }
}

//cones that will slide in the holes
module hole_cone(offset_x=0,offset_y=0,offset_z=0){
    translate([offset_x,offset_y,offset_z])
        cylinder(r1=hole_cone_base_r,
            r2=hole_cone_top_r,
            h=board_thickness*1.0,
            center=true);
}


module notch(offset_x=0,offset_y=0,offset_z=0, rotation_z=0, height=notch_height, angle=0.7){

    p0=[0,0];
    p1=[notch_thickness,0];
    p2=[notch_thickness,-height];
    p3=[notch_thickness+notch_length,-(height+notch_thickness)*angle];
    p4=[notch_thickness+notch_length,-(height+notch_thickness)];
    p5=[0,-(height+notch_thickness)];
    
    translate([offset_x,offset_y,offset_z])
    rotate([-90,0,-90+rotation_z])
    linear_extrude(height=notch_width, center=true)
    polygon([p0,p1,p2,p3,p4,p5]);
}

//base that inserts on the board
module board_base(offset_x=0,offset_y=0,offset_z=0){
    
    cone_x_offset=(board_hole_horiz_dist -board_hole_diameter)/2;
    
    cone_y_offset=(base_length/2)-hole_perimeter_to_board_edge-hole_cone_base_r-notch_thickness*1.1;
    
    cone_z_offset=(fixed_height_to_board/2)+board_thickness/4-0.001;
    
    translate([offset_x,offset_y,offset_z]){
        base_cube();
        
        hole_cone(offset_x=cone_x_offset,
            offset_y=cone_y_offset,
            offset_z=cone_z_offset);
        hole_cone(offset_x=-cone_x_offset,
            offset_y=cone_y_offset,
            offset_z=cone_z_offset);
        
        notch(0,base_length/2,fixed_height_to_board/2-0.001);
        
    }
}





module RFID(){
	//calculate size with notches
	width=RFID_width+2*(notch_thickness+tolerance);
	length=RFID_length+notch_thickness+tolerance;

	arm_width=5; // note the usb plug allows for max 5mm
	translate([arm_width/2-board_width/2,RFID_hole_to_board_distance/2-0.001+base_length/2,0])
	base_cube(arm_width,RFID_hole_to_board_distance);
	
	translate([
	width/2-board_width/2+arm_width-width,
	length/2+base_length/2+RFID_hole_to_board_distance-0.001,
	0]){
		base_cube(width,length);
		
		translate([0,length/2,fixed_height_to_board/2-0.001])
		notch();
		
		translate([width/2,0,fixed_height_to_board/2-0.001])
		notch(rotation_z=-90);
		
		translate([-width/2,0,fixed_height_to_board/2-0.001])
		notch(rotation_z=90);
	}
}





module motor_driver(){
	//calculate size with notches
	motor_board_to_board_distance=23.5;
	motor_width=35.2;
	motor_length=31.5;
	motor_height=3.4;
	width=motor_width+2*(notch_thickness+tolerance);
	length=motor_length+notch_thickness+tolerance;

	arm_width=7; 
	translate([-(arm_width/2-board_width/2),motor_board_to_board_distance/2-0.001+base_length/2,0])
	base_cube(arm_width,motor_board_to_board_distance);
	
	translate([
	(-width/2+board_width/2+width/2-arm_width/2),
	length/2+base_length/2+motor_board_to_board_distance-0.001,
	0]){
		base_cube(width,length);
		
		translate([0,length/2,fixed_height_to_board/2-0.001])
		notch(height=motor_height);
		
		translate([width/2,0,fixed_height_to_board/2-0.001])
		notch(rotation_z=-90,height=motor_height);
		
		translate([-width/2,0,fixed_height_to_board/2-0.001])
		notch(rotation_z=90,height=motor_height);
	}
}



module vl53l0x(){

	height=vl53l0x_height+height_to_board+board_thickness;
	width=5;
	vl53l0x_holes_r=(1.42/2);
	vl53l0x_outer_r=6.8/2;
	vl53l0x_width=20-vl53l0x_outer_r*2;
	vl53l0x_pin_distance=12.4+vl53l0x_holes_r*2-0.1;

	translate([0,width/2+base_length/2-0.001,(height-height_to_board)/2]){
		cube([5,width,height], center=true);

		translate([-vl53l0x_width/2,0,height/2+vl53l0x_outer_r])
		rotate([90,0,0]){

			linear_extrude(height=width, center=true)
			hull(){
				translate([vl53l0x_width,0])
				circle(r=vl53l0x_outer_r);

				circle(r=vl53l0x_outer_r);	
			}

			translate([0,0,5.7/2+width/2])
			linear_extrude(height=5.7, center =true){
				translate([vl53l0x_pin_distance,0,0])
				circle(r=vl53l0x_holes_r);

				circle(r=vl53l0x_holes_r);
			}
		}
	}
}





module complete_top(){
	board_base();
	RFID();
	motor_driver();
	vl53l0x();
}




module breadboard(){
	//calculate size with notches
	breadboard_board_to_board_distance=3.2;
	breadboard_width=85.82;
	breadboard_length=56.5;
	breadboard_height=9.9;
	
	width=breadboard_width+2*(notch_thickness+tolerance);
	length=breadboard_length+notch_thickness+tolerance;

	arm_width=15; 
	translate([0,breadboard_board_to_board_distance/2-0.001+base_length/2,0])
	base_cube(arm_width,breadboard_board_to_board_distance);
	
	translate([
	0,
	length/2+base_length/2+breadboard_board_to_board_distance-0.001,
	0]){
		base_cube(width,length);
		
		translate([0,length/2,fixed_height_to_board/2-0.001])
		notch(height=breadboard_height,angle=0.9);
		
		translate([width/2,0,fixed_height_to_board/2-0.001])
		notch(rotation_z=-90,height=breadboard_height,angle=0.9);
		
		translate([-width/2,0,fixed_height_to_board/2-0.001])
		notch(rotation_z=90,height=breadboard_height,angle=0.9);
	}
}



module complete_bottom(){
	
	translate([-100,-50,0]){
		rotate([0,0,0])
		board_base();
		
		rotate([0,0,0])
		breadboard();
	}
}


//complete_bottom();
complete_top();

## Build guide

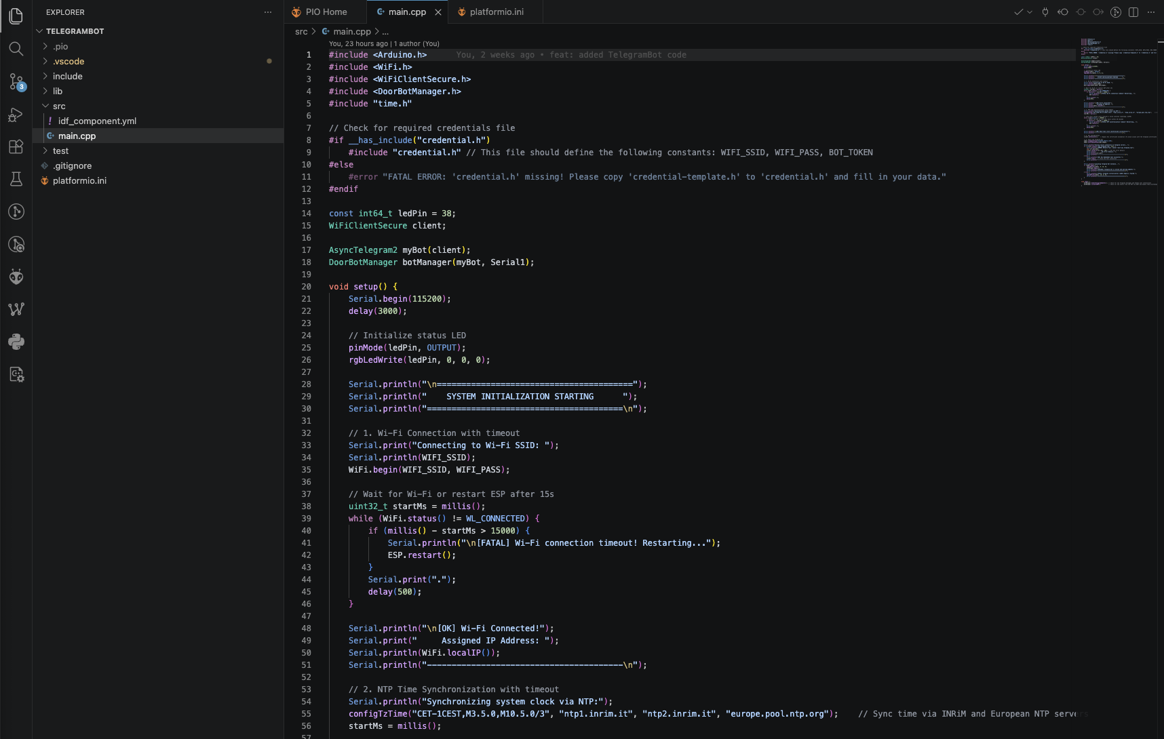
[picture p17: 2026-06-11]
RepoImages/SoftwareSetup/VSCode+PlatformIO/build-platformio-project.png

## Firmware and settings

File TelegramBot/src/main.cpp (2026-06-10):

#include <Arduino.h>
#include <WiFi.h>
#include <WiFiClientSecure.h>
#include <DoorBotManager.h>
#include "time.h"

// Check for required credentials file
#if __has_include("credential.h")
    #include "credential.h" // This file should define the following constants: WIFI_SSID, WIFI_PASS, BOT_TOKEN
#else
    #error "FATAL ERROR: 'credential.h' missing! Please copy 'credential-template.h' to 'credential.h' and fill in your data."
#endif

const int64_t ledPin = 38;
WiFiClientSecure client;

AsyncTelegram2 myBot(client);
DoorBotManager botManager(myBot, Serial1);

void setup() {
    Serial.begin(115200);
    delay(3000);

    // Initialize status LED
    pinMode(ledPin, OUTPUT);
    rgbLedWrite(ledPin, 0, 0, 0);

    Serial.println("\n========================================");
    Serial.println("    SYSTEM INITIALIZATION STARTING      ");
    Serial.println("========================================\n");

    // 1. Wi-Fi Connection with timeout
    Serial.print("Connecting to Wi-Fi SSID: ");
    Serial.println(WIFI_SSID);
    WiFi.begin(WIFI_SSID, WIFI_PASS);
    
    // Wait for Wi-Fi or restart ESP after 15s
    uint32_t startMs = millis();
    while (WiFi.status() != WL_CONNECTED) {
        if (millis() - startMs > 15000) {
            Serial.println("\n[FATAL] Wi-Fi connection timeout! Restarting...");
            ESP.restart();
        }
        Serial.print(".");
        delay(500);
    }
    
    Serial.println("\n[OK] Wi-Fi Connected!");
    Serial.print("     Assigned IP Address: ");
    Serial.println(WiFi.localIP());
    Serial.println("----------------------------------------\n");

    // 2. NTP Time Synchronization with timeout
    Serial.println("Synchronizing system clock via NTP:");
    configTzTime("CET-1CEST,M3.5.0,M10.5.0/3", "ntp1.inrim.it", "ntp2.inrim.it", "europe.pool.ntp.org");    // Sync time via INRiM and European NTP servers
    startMs = millis();
    
    // Loop until system clock receives a valid internet timestamp (>1970)
    while (time(nullptr) < 100000) { 
        // Reboot the ESP if time sync fails within 20 seconds
        if (millis() - startMs > 20000) {
            Serial.println("\n[FATAL] NTP synchronization timeout! Restarting...");
            ESP.restart();
        }
        Serial.print(".");
        delay(500);
    }
    
    Serial.println("\n[OK] Real-time clock synchronized successfully!");
    Serial.println("----------------------------------------\n");

    // 3. SSL Configuration
    client.setInsecure();   // Bypass SSL certificate validation (To avoid issues with the telegram certificate verification change)

    // 4. Start the Telegram bot
    myBot.setUpdateTime(TELEGRAM_UPDATE_TIME); 
    myBot.setTelegramToken(BOT_TOKEN);

    Serial.println("Testing secure connection to Telegram servers...");
    if (!client.connect("api.telegram.org", 443)) {
        Serial.println("[ERROR] Network Fail: Cannot reach api.telegram.org");
        char err_buf[100];
        client.lastError(err_buf, 100); // Get SSL error details
        Serial.print("        SSL Error Details: ");
        Serial.println(err_buf);
        Serial.println("----------------------------------------\n");
    } else {
        Serial.println("[OK] SSL Handshake test successful.");
        client.stop();  // Close the test connection
        Serial.println("----------------------------------------\n");
    }

    Serial.println("Launching Telegram Bot Instance...");
    if (myBot.begin()) {
        rgbLedWrite(ledPin, 0, 10, 0);
        botManager.begin();
        Serial.println("[SUCCESS] Telegram bot is online and polling updates.");
        Serial.println("========================================\n");
    } else {
        Serial.println("[FATAL] Telegram initialization (myBot.begin()) failed.");
        rgbLedWrite(ledPin, 10, 0, 0);
        Serial.println("========================================\n");
    }
}

void loop() {
    botManager.handleTelegramUpdates(); // Check for new Telegram messages and handle user interactions
    botManager.listenToMSP();           // Check for new events from the MSP via UART and handle them accordingly
}

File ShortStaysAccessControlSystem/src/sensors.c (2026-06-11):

#include "sensors.h"

// ToF sensor VL53L0X

volatile uint8_t ToF_flag = 0;
volatile bool ToF_ready = 0;



/*
    The ToF will rely solely on the GPIO interrupt,
    and the threshold for the sensor is setup via I2C read onto peripheral's registers.
    A driver for the sensor is included under 'src/external_src/drivers/'
*/



void ToF_Init(){
    xshut_gpio_init();
    i2c_init();
    interrupt_gpio_init();
    return;
}




void ToF_IRQHandler(void){
    PORT(VL53L0X_INT_PORT)->IE  &= ~ONE_HOT_BIT(VL53L0X_INT_PIN);
    PORT(VL53L0X_INT_PORT)->IFG  &= ~ONE_HOT_BIT(VL53L0X_INT_PIN);
    if(ToF_ready) ToF_flag = 1;

    return;
}



void ToF_disable(){
    PORT(VL53L0X_INT_PORT)->IE  &= ~ONE_HOT_BIT(VL53L0X_INT_PIN);
    PORT(VL53L0X_INT_PORT)->IFG  &= ~ONE_HOT_BIT(VL53L0X_INT_PIN);

    vl53l0x_stop_continuous();

    xshut_toggle(false);

    ToF_flag=0;
    ToF_ready=0;

    return;
}




void ToF_enable(){
    PORT(VL53L0X_INT_PORT)->IE  &= ~ONE_HOT_BIT(VL53L0X_INT_PIN);
    PORT(VL53L0X_INT_PORT)->IFG  &= ~ONE_HOT_BIT(VL53L0X_INT_PIN);
    ToF_flag=0;

    ToF_ready = vl53l0x_init();
    ToF_ready &= vl53l0x_start_continuous();

    if (!ToF_ready){  //if init failed
        xshut_toggle(false);

        static bool retries=RECOVER_TRIES;

        if((retries--)>0) ToF_enable();
        else {retries=RECOVER_TRIES; ToF_ready=0; return;}
    }
    else
    {
        if(!clear_interrupt()) printf("clear_interrupt error\n"); //clear sensor interrupts

        PORT(VL53L0X_INT_PORT)->IFG  &= ~ONE_HOT_BIT(VL53L0X_INT_PIN);
        PORT(VL53L0X_INT_PORT)->IE  |= ONE_HOT_BIT(VL53L0X_INT_PIN);
    }
    printf("end of T0F_enable: ToF_ready %d\n", ToF_ready);

    return;
}



// RFID MFRC522

volatile bool RFID_ready = 0;
const uint8_t RFID_saved[RFID_UID_LENGTH] = {233,52,245,162};



static void RFID_WriteRegister(uint8_t reg, uint8_t value) {
    /*
     * Bit 0 must always be 0.
     * Bit 7 (MSB) is the R/W flag: 0 for write, 1 for read.
     * */
    uint8_t addr = ((uint16_t) (reg << 1)) & 0x7E;
    uint32_t t_start =0;
    RFID_CS_Low(); // activate the CS

    // Wait for TX to complete (first byte)
    SPI_transmitData(EUSCI_B2_BASE, addr);
    t_start = system_millis;
    while (!(SPI_getInterruptStatus(EUSCI_B2_BASE, EUSCI_B_SPI_TRANSMIT_INTERRUPT))
               && ((system_millis - t_start) < SPI_TIMEOUT));
        SPI_clearInterruptFlag(EUSCI_B2_BASE, EUSCI_B_SPI_TRANSMIT_INTERRUPT);

    // Wait for TX complete (data byte)
    SPI_transmitData(EUSCI_B2_BASE, value);
    t_start = system_millis;
    while (!(SPI_getInterruptStatus(EUSCI_B2_BASE, EUSCI_B_SPI_TRANSMIT_INTERRUPT))
               && ((system_millis - t_start) < SPI_TIMEOUT));
        SPI_clearInterruptFlag(EUSCI_B2_BASE, EUSCI_B_SPI_TRANSMIT_INTERRUPT);

    while (SPI_isBusy(EUSCI_B2_BASE));
    RFID_CS_High();
}



static uint8_t RFID_ReadRegister(uint8_t reg){

    uint8_t addr = (((reg << 1) & 0x7E) | 0x80);  // MSB=1 for read
    uint8_t data = 0;
    uint32_t t_start;

    RFID_CS_Low();

    // Send address byte
    SPI_transmitData(EUSCI_B2_BASE, addr);
    t_start = system_millis;
    while (!(SPI_getInterruptStatus(EUSCI_B2_BASE, EUSCI_B_SPI_TRANSMIT_INTERRUPT))
           && ((system_millis - t_start) < SPI_TIMEOUT));
    SPI_clearInterruptFlag(EUSCI_B2_BASE, EUSCI_B_SPI_TRANSMIT_INTERRUPT);

    // Read dummy byte (discard) – this clocks out the first byte
    t_start = system_millis;
    while (!(SPI_getInterruptStatus(EUSCI_B2_BASE, EUSCI_B_SPI_RECEIVE_INTERRUPT))
           && ((system_millis - t_start) < SPI_TIMEOUT));
    (void) SPI_receiveData(EUSCI_B2_BASE);
    SPI_clearInterruptFlag(EUSCI_B2_BASE, EUSCI_B_SPI_RECEIVE_INTERRUPT);

    // Send 0x00 to clock out the actual register value
    SPI_transmitData(EUSCI_B2_BASE, 0x00);
    t_start = system_millis;
    while (!(SPI_getInterruptStatus(EUSCI_B2_BASE, EUSCI_B_SPI_TRANSMIT_INTERRUPT))
           && ((system_millis - t_start) < SPI_TIMEOUT));
    SPI_clearInterruptFlag(EUSCI_B2_BASE, EUSCI_B_SPI_TRANSMIT_INTERRUPT);

    // Read the actual data
    t_start = system_millis;
    while (!(SPI_getInterruptStatus(EUSCI_B2_BASE, EUSCI_B_SPI_RECEIVE_INTERRUPT))
           && ((system_millis - t_start) < SPI_TIMEOUT));
    data = SPI_receiveData(EUSCI_B2_BASE);
    SPI_clearInterruptFlag(EUSCI_B2_BASE, EUSCI_B_SPI_RECEIVE_INTERRUPT);

    while (SPI_isBusy(EUSCI_B2_BASE));

    RFID_CS_High();
    return data;
}



static bool MFRC522_SoftReset(void) {
    RFID_WriteRegister(MFRC522_COMMAND_REG, MFRC522_CMD_SOFT_RESET);
    // Wait for the PowerDown bit to clear (bit 4 of CommandReg)
    uint32_t t_start = system_millis;
    while ((system_millis - t_start) < 200) {
        if (!(RFID_ReadRegister(MFRC522_COMMAND_REG) & 0x10)) //bit4 (fifth bit) must be 0 when ready
            return true;
    }
    return false;
}



static void MFRC522_AntennaOn(void) {
    uint8_t temp = RFID_ReadRegister(MFRC522_TX_CONTROL_REG);
    if (!(temp & 0x03)) {
        RFID_WriteRegister(MFRC522_TX_CONTROL_REG, temp | 0x03);
    }
}
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

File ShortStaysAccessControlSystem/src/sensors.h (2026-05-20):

#ifndef SENSOR_ToF_H
#define SENSOR_ToF_H

#include <ti/devices/msp432p4xx/driverlib/driverlib.h>
#include <stdio.h>
#include <stdint.h>
#include <stdbool.h>
#include "vl53l0x.h"
#include "timers.h"

////////////////// VL53L0X /////////////////////////
extern volatile uint8_t ToF_flag;
extern volatile bool ToF_ready; // 1=yes 0=no

void ToF_Init(void);
void ToF_IRQHandler(void);
void ToF_disable(void);
void ToF_enable(void);


//////////////////// RFID /////////////////////////

/* *the display uses SPI on UCB0
 * *the esp uses the UCA2 with UART
 * *the VL53L0X uses the UCB1 with I2C
 * *the RFID uses the UCB2 with SPI
 * */

extern volatile bool RFID_ready; // 1=yes 0=no

#define RECOVER_TRIES 2
#define SPI_TIMEOUT 100
#define RFID_UID_LENGTH  4          // length of the RFID UID
extern const uint8_t RFID_saved[RFID_UID_LENGTH];


void RFID_CS_Low(void);
void RFID_CS_High(void);
bool RFID_Init(void);                    // Configure SPI pins and module (module disabled initially)
bool RFID_Enable(void);                  // Enable SPI, HW init MFRC522 (soft reset, timer, antenna)
bool RFID_Disable(void);                 // Power down MFRC522, disable SPI module
bool RFID_ReadTag(uint8_t *uid, uint8_t *uidLength); // Polling single tag read (REQA -> anticollision)


#define RFID_SCK_PORT         GPIO_PORT_P3
#define RFID_SCK_PIN          GPIO_PIN5
#define RFID_MOSI_PORT        GPIO_PORT_P3
#define RFID_MOSI_PIN         GPIO_PIN6
#define RFID_MISO_PORT        GPIO_PORT_P3
#define RFID_MISO_PIN         GPIO_PIN7

/* CS active low */
#define RFID_CS_PORT          GPIO_PORT_P5
#define RFID_CS_PIN           GPIO_PIN2

/* If pulled low, hard power down triggers, when edge rising, reset is forced*/
#define RFID_RST_PORT         GPIO_PORT_P3
#define RFID_RST_PIN          GPIO_PIN0

#define RFID_EUSCI_TX_INT     EUSCI_B_SPI_TRANSMIT_INTERRUPT
#define RFID_EUSCI_RX_INT     EUSCI_B_SPI_RECEIVE_INTERRUPT

// --- MFRC522 USED REGISTER ADDRESSES ---
    //starts and stops command execution
    #define MFRC522_COMMAND_REG     0x01
    //enable and disable interrupt request control bits
    #define MFRC522_COM_I_EN_REG    0x02

    //input and output of 64 byte FIFO buffer
    #define MFRC522_FIFO_DATA_REG   0x09
    //number of bytes stored in the FIFO buffer
    #define MFRC522_FIFO_LEVEL_REG  0x0A

    //miscellaneous control registers
    #define MFRC522_CONTROL_REG     0x0C
    //adjustments for bit-oriented frames
    #define MFRC522_BIT_FRAMING_REG 0x0D
    //defines general modes for transmitting and receiving
    #define MFRC522_MODE_REG        0x11

    //controls the logical behavior of the antenna driver pins TX1 and TX2
    #define MFRC522_TX_CONTROL_REG  0x14
    //selects the internal sources for the antenna driver
    #define MFRC522_TX_ASK_REG      0x15
    //configures the receiver gain
    #define MFRC522_RF_CFG_REG      0x26

    //defines settings for the internal timer
    #define MFRC522_T_MODE_REG      0x2A
    #define MFRC522_T_PRESCALER_REG 0x2B
    //defines the 16-bit timer reload value
    #define MFRC522_T_RELOAD_H_REG  0x2C
    #define MFRC522_T_RELOAD_L_REG  0x2D

    //shows the software version
    #define MFRC522_VERSION_REG     0x37

    //defines the width of the Miller modulation as multiples of the carrier
    //frequency (ModWidth + 1 / fclk)
    // the maximum value is half the bit period
    #define MFRC522_MOD_WIDTH_REG       0x24

    //Interrupt request bits.
    #define MFRC522_COM_IRQ_REG         0x04

// --- MFRC522 COMMANDS ---
    //no action, cancels current command execution
    #define MFRC522_CMD_IDLE        0x00
    //resets the MFRC522
    #define MFRC522_CMD_SOFT_RESET  0x0F
    //transmits data from the FIFO buffer
    #define MFRC522_CMD_TRANSMIT    0X04
    //transmits data from FIFO buffer to antenna and automatically
    // activates the receiver after transmission
    #define MFRC522_CMD_TRANSCEIVE  0x0C
    //activates the receiver circuits
    #define MFRC522_CMD_RECEIVE     0x08
    //performs the MIFARE standard authentication as a reader
    #define MFRC522_CMD_MF_AUTHENT  0x0E

#endif

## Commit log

2026-03-17 Added buzzer and idle functionalities
    [buzzer.c, fsm.c, irqHandlers.c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]
2026-03-25 Added VL53L0X sensor support and various fixes
    [fsm.c, irqHandlers.c, push_button.c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]
2026-04-01 fixed system freeze caused by the RTC module failing to synchronize
    [fsm.c]
2026-04-20 attivato il submodule recurse true di git
2026-04-20 Included vl53l0x driver
2026-04-26 Reordered some code and fixed some bugs
    [comm_esp.c, display.h, fsm.c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]
2026-04-26 Added some define for Sensor config
2026-04-29 removed test uart
2026-04-29 Added better error handling and ToF_ready flag
    [fsm.c, fsm_helpers.c]
2026-05-04 Fixed misplacing of i2c routines
    [comm_esp.c, fsm.c, fsm_helpers.c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]
2026-05-05 Fixed some small bugs
    [sensors.c]
2026-05-10 Added RFID, PWM sounds and some idle fixes
    [buzzer.c, display.h, fsm.c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]
2026-05-11 Added volume control to pwm, and optimized it's execution
2026-05-21 Sensor works
2026-05-25 move Display driver files into src folder
2026-05-25 removedsimplelink SDK from the repo
    [benchloop.cfg, bigtime.cfg, build.cfg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]
2026-05-25 feat: added 3D models for project demo
    [All components.3mf, door.stl, doorframe.3mf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]
2026-05-25 refactor: secure credentials and improve network stability
    - Implement credential-template.h to protect sensitive data
    - Add self-healing timeouts for Wi-Fi and NTP connections
    - Bypass expired SSL certs and add network diagnostic logging
    - Update AsyncTelegram2 and fix .vscode tracking in gitignore
    [main.cpp]
2026-05-26 Added LPM0 interrupt toggle and fixed some UI responsiveness bugs
    [fsm.c, fsm_helpers.c, irqHandlers.c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]
2026-06-10 Fixes for time sync and door locked state
    [fsm.c, fsm_helpers.c]
2026-06-10 added .scad and stl for peripherals 3d printed structures
    [sensors_and_peripherals_supports.scad, sensors_and_peripherals_supports.stl]
2026-06-10 updated scad script
    [sensors_and_peripherals_supports.scad]
2026-06-10 Fixed a small clock bug
    [fsm.c]
2026-06-10 fixed database hour and motor consumptions
    [fsm_helpers.c, motor.c]
2026-06-10 Fixed systick not counting when in LPM0 and removed fn_SYNC_TIME
    [fsm.c, fsm_helpers.c, irqHandlers.c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]
2026-06-11 fixed merge conflict signs
    [fsm.c]
2026-06-11 feat: improved README.md structure and added ESP32-S3 UART Communication point in HardwareSetup section
2026-06-11 Minor fixes and otimizations
    [fsm.c, fsm_helpers.c, irqHandlers.c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]
2026-06-12 Fixed a small bug when sync was taking place and the MCU goes to sleep without checking inputs in-between
    [fsm.c]
2026-06-12 Added RFID, Buzzer and VL53L0X to README. Added the FSM diagram
    [buzzer.c]
2026-06-12 Update README.md
    added motor info
2026-06-13 Update README.md
    Add motor info
2026-06-13 Updated openscad script
    [sensors_and_peripherals_supports.scad, sensors_and_peripherals_supports.stl, sensors_and_peripherals_supports_bottom.stl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]
2026-06-15 fix: enhance user management and command handling in DoorBotManager
    [comm_esp.c]
2026-06-15 refactor: improve UART command handling and interrupt processing
2026-06-16 refactor: remove temporary pin state from user access flow
2026-06-16 fix: resolve merge conflicts and clean up motor control function documentation
2026-06-17 Update README with proximity detection and error handling
    Added code snippet for proximity detection flow and clarified error checks.
